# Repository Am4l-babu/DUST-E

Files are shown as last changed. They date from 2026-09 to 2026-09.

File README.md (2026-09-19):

# DUST-E

### The Uncooperative Waste Management System

A trash can that is technically intelligent and deliberately unhelpful.

It detects you. It looks at you. It opens for your rubbish, comments on your
throwing, and takes commands from a large industrial remote control that it
almost never obeys. There is a big illuminated button on the front labelled
**NORMAL MODE**. Press it and the bin becomes an ordinary, well-behaved
automatic dustbin — for about four seconds. Then a small hatch opens, a
comically oversized mechanical finger emerges, switches NORMAL MODE off, and
retracts.

That is the whole project. It works, it is safe, and it took a genuinely
unreasonable amount of engineering.

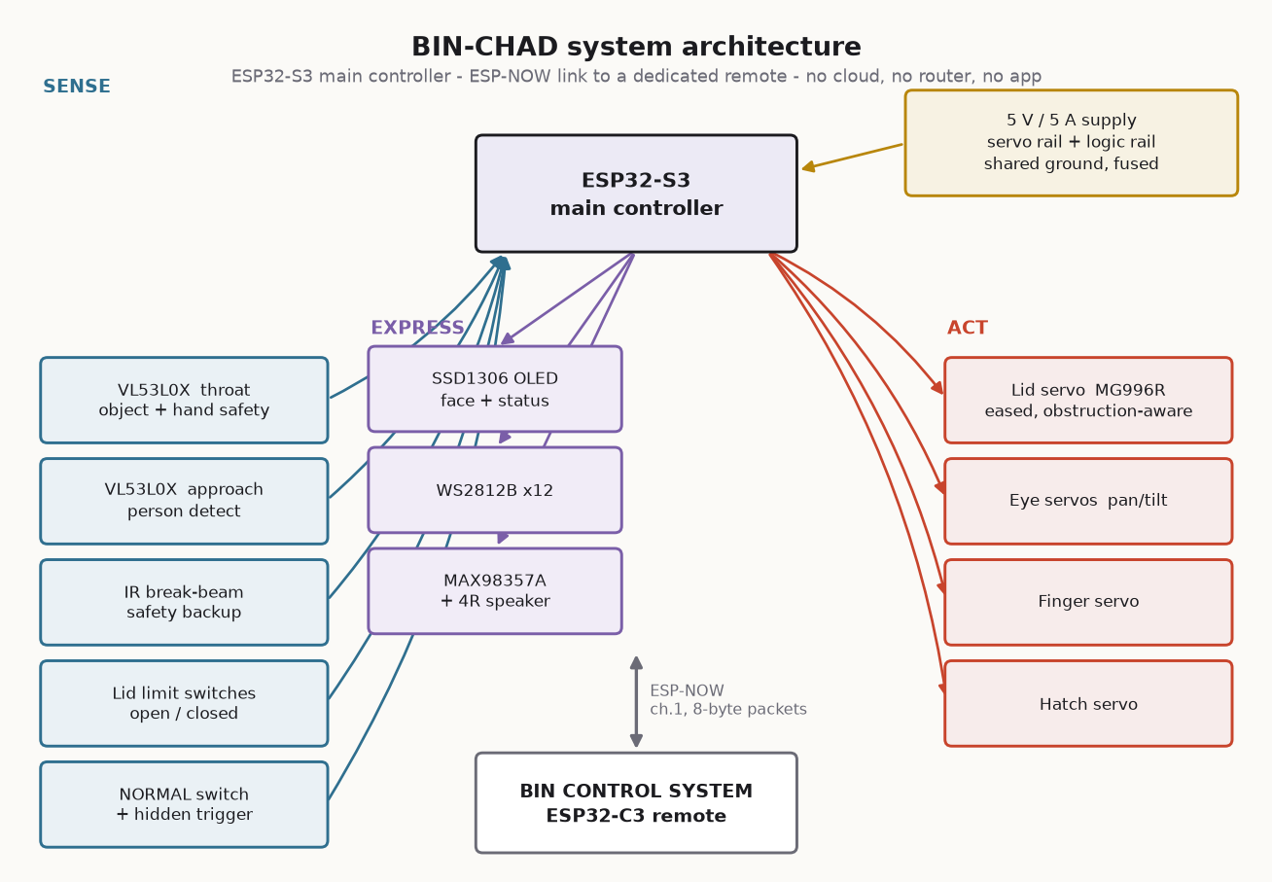
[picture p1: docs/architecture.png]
System architecture


---

## What is in this repository

| Path | Contents |
|---|---|
| `firmware/DustE/` | Main controller firmware (ESP32-S3). Arduino sketch, modular `src/` tree. |
| `firmware/DustERemote/` | Remote firmware (ESP32-C3). |
| `firmware/DustEWeb/` | The web remote: a second, simpler machine (ESP32 + L298N + two DC motors) that serves its own browser dashboard. The phone is its remote, its speaker and its eyes. See its [README](firmware/DustEWeb/README.md) and [PROTOCOL](firmware/DustEWeb/PROTOCOL.md). |
| `firmware/DustECam/` | Optional ESP32-CAM companion for the web remote: serves snapshots the phone runs its detector on. [README](firmware/DustECam/README.md). |
| `firmware/DustEBody/` | **In progress:** body controller firmware for the XIAO ESP32-S3 - motors, lid, LEDs, and the reflex safety that has the last word on anything that moves. [README](firmware/DustEBody/README.md). |
| `firmware/DustESensorNode/` | **In progress:** the UNO Q's own sensor firmware - HC-SR04 fan, IR throat, and the MOTION_OK safety pulse the XIAO body relies on. [README](firmware/DustESensorNode/README.md). |
| `brain/` | **In progress:** the autonomous-companion brain for the Arduino UNO Q (Python). Phase 1 (vision) done; Phase 2 (XIAO body link, safety validator, DRIVE/HW/DEBUG dashboard) nearly done. [README](brain/README.md). |
| `docs/COMPANION_ARCHITECTURE.md` | Analysis and phased plan for evolving the bin into an autonomous companion: reuse, conflicts, missing hardware, protocol, safety. |
| `docs/COMPANION_BOM.md` | Shopping list for the companion upgrade: what to buy per phase, sourced links, and why each part removes a specific failure. |
| `audio/` | The voice clips. The web remote's filesystem image ships them; more can be uploaded from its AUDIO tab. |
| `cad/` | Parametric OpenSCAD source for all 24 printed parts. |
| `docs/` | Generated diagrams (regenerate with `python tools/render_docs.py`). |
| `tools/` | Diagram renderer, WAV generator, and a static consistency checker. |
| `tests/` | Standalone bench bring-up sketches, one board/part at a time (not the `brain/` pytest suite). `xiao_motor_test/` (XIAO ESP32-S3 + L298N, `pio run` builds) and `cam_tilt_test/` (UNO Q camera tilt servo, D11, `arduino-cli compile` builds) are current; `l298n_motor_test/` and `obstacle_avoid_test/` are superseded records of the earlier UNO Q-driven wiring. |
| `BOM.csv` | Full bill of materials with prices and search links. |
| `PINOUT.md` | Exact GPIO map for both boards, plus the pins you must not touch. |
| `WIRING.md` | Power budget, distribution, connection tables, the servo cutoff circuit. |
| `BUILD_GUIDE.md` | Step-by-step assembly and calibration. |
| `CAD_README.md` | Every printed part: dimensions, print settings, the torque budget. |
| `FIRMWARE_README.md` | Module-by-module architecture, build setup, tuning. |
| `REMOTE_PROTOCOL.md` | ESP-NOW packet format and the mistranslation engine. |
| `TEST_PLAN.md` | Endurance, safety and reliability test checklist. |
| `TROUBLESHOOTING.md` | The eight failures you are actually going to hit. |
| `DEMO.md` | The two-minute demo script and the failure-proofing. |

---

## The five things it does

**1. It watches you.**
A VL53L0X pointing into the room notices someone approaching. The servo-mounted
eyeball turns toward them. The OLED says `OH NO.`

**2. It reacts to your throw.**
A second VL53L0X looks down the bin's throat. The lid opens on detection
(< 300 ms), waits, and decides whether the object actually went in.
It did: *"Acceptable."* It did not: two full seconds of silence, direct eye
contact, then *"My grandmother throws better."*

**3. It disobeys the remote.**
A dedicated ESP32-C3 remote — oversized, antenna'd, labelled
**PLEASE DO NOT TRUST** — sends honest ESP-NOW packets. The bin runs them
through a deterministic mistranslation engine: OPEN closes, CLOSE opens, LEFT
looks right, STOP makes everything faster, MUTE turns the volume up. The more
you press, the less it complies.

**4. It disables its own NORMAL MODE button.**
The signature mechanism. Documented in full in §"The punchline" below.

**5. It never hurts anyone.**
The lid is eased at both ends and cannot slam. Two independent sensors watch
the closing zone; either one stops the lid and reverses it, and the bin
apologises — the one thing it is never sarcastic about. Limit switches verify
both endpoints rather than trusting the servo angle. A master switch and a
firmware-controlled MOSFET both cut actuator power, and the safe state is the
default state.

---

## The punchline

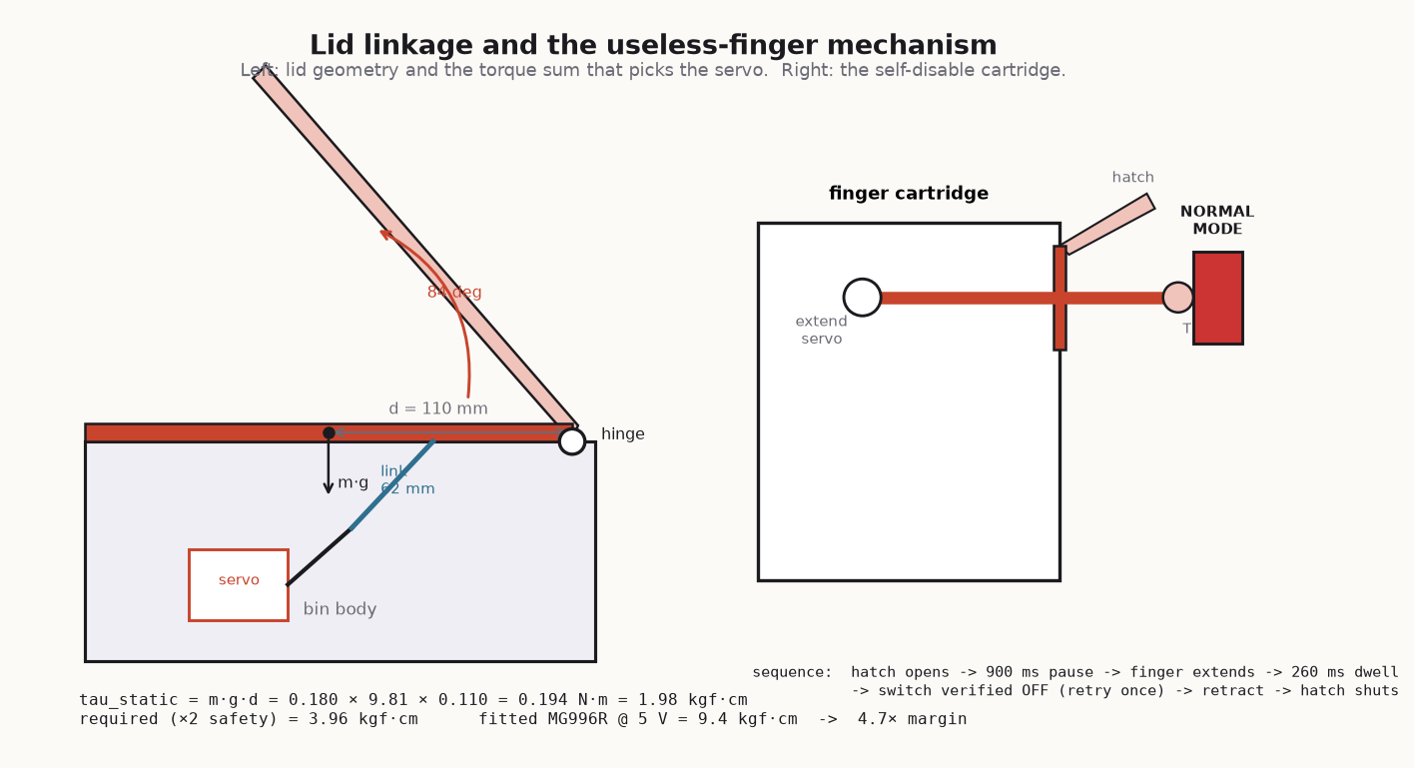
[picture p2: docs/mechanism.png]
Lid and finger mechanism


```
   user presses NORMAL MODE
            ↓
   bin becomes a completely normal automatic bin
            ↓
   ~4.5 seconds pass. The lid opens and closes properly. It is well behaved.
            ↓
   the eye turns, slowly, to look at the button
            ↓
   900 ms of nothing
            ↓
   a hatch opens in the front panel
            ↓
   900 ms of nothing (this pause is the joke)
            ↓
   an absurd finger extends and flips the switch OFF
            ↓
   the finger verifies the switch actually moved, and retries once if not
            ↓
   finger retracts, hatch closes
            ↓
   display:  NORMAL MODE CANCELLED
```

The eye looking at the button first is deliberate: telegraphing the move is
what turns a mechanism into a joke.

---

## The second machine: the web remote

`firmware/DustEWeb/` is a different build of the same idea. Instead of an
oversized labelled remote there is no remote at all — the ESP32 serves a
dashboard and your phone becomes the thing it disobeys.

It is a deliberately smaller machine: **ESP32 + L298N + two DC motors**, and
nothing else is required or pretended to exist. It drives, it argues, and it
files a written report about why it went the other way.

```
phone ──Wi-Fi / BLE / USB──> ESP32 ──> L298N ──> two motors
  │  ▲                         │
  │  └─ "play this" ───────────┼── sound bank    (31 events -> clips you upload)
  └──── "I saw a person" ─────┼── vision intake (the detector runs on the phone)
                               ├── web server + WebSocket
                               ├── personality engine  (7 traits, 9 moods)
                               └── safety layer        (has the last word)
```

The phone is the speaker and the eyes as well as the remote. Clips are
uploaded from the dashboard's AUDIO tab and assigned to events; the bin only
ever sends a tiny "play this" message, over Wi-Fi, Bluetooth and USB at once.
The VISION tab runs a person-and-object detector in the browser, on the
phone's camera or on an ESP32-CAM's snapshots, and reports what it saw.

The same priority order applies, and it shows up in the code rather than in
the marketing: the safety layer runs *before* the personality engine and
cannot be reached by it. STOP always stops, the controls are hold-to-drive,
the motors cut if the browser goes quiet for 1.5 seconds, and the dashboard
reports `BATTERY — NOT INSTRUMENTED` rather than inventing a percentage for a
sensor that is not fitted.

Built and verified with PlatformIO — `pio run` in that folder, then
`pio run -t uploadfs` for the dashboard. Full details, including the six
places where it deliberately departs from a literal reading of the brief, are
in [firmware/DustEWeb/README.md](firmware/DustEWeb/README.md).

---

## Design rules this project follows

**Serious engineering, ridiculous purpose.** Every subsystem is built as if it
mattered. None of it matters.

**The machine is the attraction.** No app, no cloud, no router, no dashboard.
ESP-NOW is peer-to-peer; unplug the venue's Wi-Fi and nothing changes.
(`firmware/DustEWeb/` deliberately trades this away for a browser
dashboard — but it carries its own access point, so it still needs nothing
from the venue.)

**Comedy never overrides safety.** The priority order, applied to every design
decision in this repo:

```
SAFETY → RELIABILITY → PHYSICAL COMEDY → MECHANICAL QUALITY
       → DEMO SPEED → VISUAL APPEAL → TECHNICAL COMPLEXITY
```

**Nothing blocks.** There is not a single `delay()` after `setup()` returns.
Everything is a `millis()` state machine, because the lid must keep checking
for fingers while audio plays, LEDs animate and packets arrive.

**Nothing is glued.** Every module comes out on M3 screws into heat-set
inserts. The electronics tray slides out of the back with the loom attached.
The lid lifts off by pulling one hinge pin. You will be debugging this on a
table with ten minutes to go.

**It degrades instead of failing.** A dead ToF sensor sets a flag and the bin
carries on. A missing WAV file is silent, not a crash. A lost remote produces
`REMOTE LOST / Good.` A lid fault shows `Have you tried turning me off?` and
keeps the rest of the machine alive.

---

## Quick start

```bash
# 1. Print the parts (see CAD_README.md for the plate order and settings)
openscad -o lid_frame.stl -D 'part="lid_frame"' cad/lid_mechanism.scad

# 2. Wire it (PINOUT.md, then WIRING.md)

# 3. Prepare the sounds
python tools/make_wavs.py            # generates placeholder clips into firmware/DustE/data/

# 4. Flash the bin
#    Arduino IDE -> firmware/DustE/DustE.ino
#    Board: ESP32S3 Dev Module | USB CDC On Boot: Enabled
#    Then: Tools -> ESP32 Sketch Data Upload  (writes data/ to LittleFS)

# 5. Flash the remote
#    Arduino IDE -> firmware/DustERemote/DustERemote.ino
#    Board: ESP32C3 Dev Module | USB CDC On Boot: Enabled

# 6. Calibrate (BUILD_GUIDE.md §7) - servo endpoints, then ToF thresholds

# Any time you edit a pin map, protocol.h, or settings.h:
python tools/verify_project.py       # duplicate GPIOs, diverged protocol
                                     # copies, undefined methods, broken doc
                                     # links, bad WAVs, contradictory settings
```

Build it in the order given in `BUILD_GUIDE.md` §1. One subsystem at a time,
each one tested before the next goes on. Wiring the whole thing and then
flashing it is how you end up debugging five problems at once at 3 a.m.

---

## Status and scope

**In the base build, and working:** lid with soft-close and obstruction
detection, dual ToF sensing, servo eye, OLED face, LED patterns, I²S audio,
the finger mechanism, the ESP-NOW remote, the mistranslation engine, the
personality state machine, self-test, and the hidden demo trigger.

**Deliberately optional** (in `README` terms: do not build these until the base
machine is boring and reliable):

- Camera-based face tracking and thrown-object detection (`OV2640`)
- Trajectory prediction
- Voice input
- Multiple stored personalities and per-user memory

The base machine must work with the camera physically removed. That is not a
style preference — it is the difference between a demo that survives a badly
lit conference hall and one that does not.

**Not verified here:** the DUST-E and DustERemote firmware has not been
compiled and the OpenSCAD has not been rendered in this environment — no
toolchain was available for them. (`firmware/DustEWeb/` is the exception:
it builds clean with no warnings under PlatformIO, and its LittleFS image
packs. It has not been run on hardware.) Treat the
first build as a bring-up, and expect to fix a missing include or a tight
tolerance. Every module was written against the documented library APIs and
reviewed by hand.

---

## Naming

The robot is **DUST-E**, and so is every machine in this repository: the bin
(`firmware/DustE`), its remote (`firmware/DustERemote`), the web rover
(`firmware/DustEWeb`), its camera (`firmware/DustECam`) and the brain
(`brain/dustebrain`). The name is drawn in
`display.cpp::bootScreen()` and on the remote's faceplate label.

People are expected to ask *"why does this exist?"*

The answer is: because we could build it.

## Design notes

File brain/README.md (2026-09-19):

# BRAIN

### The part of the trash bin that has opinions

The high-level brain of the DUST-E companion. It runs on the
**Arduino UNO Q's Linux side**: it sees, remembers, and decides. The ESP32 body
executes, and has the last word on anything that moves.

The full design, including why things are split this way, is in
[../docs/COMPANION_ARCHITECTURE.md](../docs/COMPANION_ARCHITECTURE.md).

**Status: phase 1 done, phase 2 nearly done.** Phase 1 is the camera,
detection, tracking and world model: it prints what the robot would believe
about the room. Phase 2 is the link to the XIAO ESP32-S3 body: the wire
protocol, the command validator, a Python reference implementation of the
body's reflex safety (section 7), `BodyLink` (section 8) - the real client -
and now the DRIVE + HW + DEBUG dashboard (section 9). `firmware/DustESensorNode/`
has been compiled and flashed on a real UNO Q (19 Sep 2026 - see its own
README section 5); `firmware/DustEBody/` still only builds, no XIAO has run
it yet. Nothing has driven a real motor.

```
USB camera ─► latest-frame grabber ─► detector (ONNX, ≤ 5 Hz) ─► torso signature
          ─► tracker ─► world model ─► events + LLM summary
```

---

## 1. What it tells you

```
[        0] VISION_ONLINE
[      400] PERSON_DETECTED      #1 4.8 m right FAR UNKNOWN
[     1200] PERSON_APPROACHING   #1 4.4 m right FAR APPROACHING
[     3600] PERSON_ZONE_CHANGED  #1 2.9 m ahead NOTICE APPROACHING previous=FAR
[     6200] PERSON_ZONE_CHANGED  #1 ~1.4 m ahead INTERACTION APPROACHING previous=APPROACH
[    11200] PERSON_WALKING_AWAY  #1 ~1.9 m ahead APPROACH WALKING_AWAY
[    13000] PERSON_LEAVING       #1 3.1 m ahead FAR WALKING_AWAY
[    17600] PERSON_LOST          #1 last_zone=FAR seen_for_s=14.6
```

`~` means the distance is an estimate the camera cannot vouch for (§4).

| Event | Meaning |
|---|---|
| `PERSON_DETECTED` | A new person, confirmed over several frames. One false-positive frame never gets greeted. |
| `PERSON_RETURNED` | Someone whose departure was announced is back: the "you again?" moment. |
| `PERSON_APPROACHING` / `PERSON_WALKING_AWAY` | Their own motion, with the robot's own motion subtracted once body telemetry exists. |
| `PERSON_LEAVING` | Walking away **and** beyond the notice zone. |
| `PERSON_LOST` | Out of view for `person_lost_s` (2.5 s). A detector blink is not a departure. |
| `PERSON_ZONE_CHANGED` | FAR / NOTICE / APPROACH / INTERACTION / TOO_CLOSE, with hysteresis. |
| `OBJECT_DETECTED` | A class not seen in the last 8 s. The same cup is news once. |
| `VISION_OFFLINE` | The camera went quiet. The summary then says *unknown*, never *nobody*. |

---

## 2. Run it

### Without any hardware (any PC with Python 3.10+)

```bash
cd brain
pip install numpy pyyaml pytest
python -m pytest                                   # 55 tests, no camera, no model
python -m dustebrain.apps.vision_node --sim walk_in  # a scripted person
```

Scenarios: `walk_in`, `flicker`, `returning`, `two_people_swap`,
`robot_drives_to_statue`, `person_with_cup`. Add `--realtime` to watch at real
speed, and `--snapshot 1` to print the LLM summary every second.

### On the UNO Q

```bash
sudo apt install python3-opencv python3-numpy python3-yaml python3-pytest
cd brain
python3 -m pytest
python3 -m dustebrain.apps.vision_node --bench 50      # acceptance: >= 3 Hz
python3 -m dustebrain.apps.vision_node --snapshot 2    # live
```

The camera goes through the **powered USB-C hub**: the UNO Q has one USB-C
port, and the camera, the ESP32 link and the microphone all need it.

Other flags: `--source clip.mp4` replays a recording at its own frame rate,
`--show` draws the tracks in a window (needs a display), `--serve 8081` does
the same drawing but serves it as an MJPEG stream any browser can open - the
one that matters on a headless UNO Q, where `--show` has no display to open -
and `--jsonl events.jsonl` keeps every event for later. `--show` and `--serve`
can run together; both draw from the same `_annotate()` call, so the bench
window and the browser tab show identical frames.

Verified against a real camera and a real HTTP client (19 Sep 2026, `--serve`
only - no UNO Q involved, a laptop webcam): `/` serves a page pointing at
`/stream.mjpg`, `/snapshot.jpg` returns a real, decodable JPEG matching the
camera's actual resolution, and `/stream.mjpg` delivers a live
multipart-replace stream. `brain/tests/test_vision_stream.py` covers the same
ground with synthetic frames, no camera required.

---

## 3. Detector model

Not committed: it is a binary, and its licence is its own. Export on a PC, not
on the board:

```bash
pip install ultralytics
yolo export model=yolov8n.pt format=onnx imgsz=320 opset=12 simplify=True
# copy yolov8n.onnx to brain/models/yolov8n-320.onnx
```

YOLOv8/YOLO11 (`[1, 84, N]`) and YOLOv5 (`[1, N, 85]`) output layouts are both
decoded. If you use a model with other classes, set `detector.labels` to its
class list in export order. The decoder refuses a label count that does not
match the tensor instead of guessing.

**Licence:** Ultralytics weights are AGPL-3.0. YOLOX-nano and NanoDet are
Apache-2.0 alternatives with the same box format, if that matters for you.

`detector.backend: none` runs the node with no detector at all. It then
reports no people, which in that configuration is the truth.

---

## 4. Calibration that actually matters

Distance comes from geometry, so these four numbers in `config/default.yaml`
(or your override file) decide whether "1.5 m" means 1.5 m:

| Key | How to get it |
|---|---|
| `camera.hfov_deg`, `camera.vfov_deg` | From the camera's datasheet, or measure: tape a 1 m ruler flat at a known distance and see how much of the frame it fills. |
| `geometry.camera_height_m` | Floor to lens, with the robot on its wheels. |
| `geometry.camera_pitch_deg` | Positive when tilted up. A phone inclinometer on the camera body is good enough. |

Then check: stand at 3 m with your feet in frame. The log should say ~3.0 m,
without a `~`.

**The honest limit.** A camera at bin height cannot see a whole standing
person up close. With the defaults (43° vertical FOV, 0.6 m, 5° up), feet leave
the frame at about 2 m. Closer than that, the estimate falls back to shoulder
width and is marked unreliable, but it is clamped to that 2 m bound. It can be
wrong, but not wrong in the direction that walks the robot into someone. A
wide-angle camera (VFOV ≥ 55°) moves the limit in. Collisions are the body's
range sensors' job, never the camera's.

---

## 5. Layout

| Path | Contents |
|---|---|
| `config/default.yaml` | Every threshold. The only place defaults live. |
| `dustebrain/config.py` | Loader: merges overrides, rejects unknown/missing keys, validates contradictions. |
| `dustebrain/events.py` | The event vocabulary for all phases. |
| `dustebrain/prng.py` | Bit-exact port of the firmware's xorshift32, so behaviour stays reproducible from a seed. |
| `dustebrain/vision/camera.py` | Latest-frame grabber thread, reconnect, file replay. |
| `dustebrain/vision/detector.py` | ONNX YOLO via `cv2.dnn` or onnxruntime; numpy decode + NMS. |
| `dustebrain/vision/appearance.py` | Torso colour histogram for short-term re-identification. RAM only. |
| `dustebrain/vision/tracker.py` | Association, track lifecycle, distance smoothing, radial velocity. |
| `dustebrain/vision/geometry.py` | Bearing, and ground/height/width distance with honest bounds. |
| `dustebrain/vision/stream.py` | `VisionStreamServer` - MJPEG-over-HTTP, viewable in a plain browser `<img>` tag. For a headless UNO Q, where `--show`'s local OpenCV window has no display to open. |
| `dustebrain/world/model.py` | People, identity across track breaks, zones, motion, objects, events, summaries. |
| `dustebrain/sim/scenario.py` | Deterministic scripted scenarios through the real geometry. |
| `dustebrain/apps/vision_node.py` | The phase-1 entry point. |
| `dustebrain/body/protocol.py` | Brain-to-body wire format: JSON lines, CRC-16, sequence numbers, a reader that survives boot-log noise. |
| `dustebrain/body/validator.py` | Source policy (the LLM cannot ask for a wheel speed), range clamps, rate limits, lower-only ceilings. |
| `dustebrain/body/simbody.py` | The body's reflex safety in Python: the reference the XIAO firmware is written against. |
| `dustebrain/body/link.py` | `BodyLink` - the real client: validate, frame, write; read, decode, update state. `SerialTransport` (pyserial) for the real port, `LoopbackPipe` for testing with no board. |
| `dustebrain/apps/body_probe.py` | Bring-up CLI: `--drive L R`, `--estop`, `--reset-estop`, a live status line. See firmware/DustEBody/README.md section 6. |
| `tests/` | One file per module; `test_world_model.py` is the phase-1 acceptance suite. |

Importing `dustebrain` does not import OpenCV. Only the camera, the detector
backends and `--show` do, so everything else runs on a machine with nothing
but numpy.

---

## 6. Verified how

- `python -m pytest`: 106 passed on Windows, Python 3.12, numpy 2.4 (no OpenCV
  installed, which is the point).
- Every `--sim` scenario produces the expected event sequence.
- With `opencv-python-headless` 5.0 in a clean virtualenv: the letterbox puts
  pixels exactly where the decoder expects, and a generated video replays
  through the camera thread and the full live loop (a colour-threshold
  stand-in for the model) to a clean exit.

**Not verified:** anything on a UNO Q, a real USB webcam, a real ONNX model
through `cv2.dnn` or onnxruntime, or detector speed on the A53 cores. The first
run on the board is a bring-up: run `--bench` before trusting `--snapshot`.

---

## 7. Phase 2: the body link

The XIAO is the only thing that can energise a motor, so its rules are the ones
that matter. They are written here first, in Python, so the failsafe matrix can
be tested before a wire is soldered - and so the firmware has an exact
specification instead of a paragraph of prose.

**The wire format** is one JSON object per line with a CRC:

```
{"v":1,"seq":1042,"t":583211,"type":"vel","l":35,"r":31,"ttl":300}*7A3F
```

Readable in a serial monitor on purpose: when the robot misbehaves at a demo,
the diagnosis has to be visible in a terminal. The CRC is there because the USB
line shares a chassis with motor wiring. A corrupted line is dropped and
counted, never guessed at, and the reader skips the ESP32 boot log without
complaining.

**The validator** is the box between everything clever and everything physical:

| Rule | Why |
|---|---|
| `vel` from `src: "llm"` is refused | The model may ask to look at someone; it may not ask for a wheel speed. Enforced in code, not in a prompt. |
| `reset_estop` only from `src: "manual"` | Clearing an emergency stop is a human decision. |
| `estop` from anyone, never rate limited | Stopping is always allowed. |
| Autonomous speed capped below manual | 45 % against 70 % by default. |
| `limits` may only **lower** a ceiling | No message in this protocol raises one. |

**The reflex safety** (`simbody.py`), in the order the body applies it:
E-stop latch, battery critical, link timeout, command TTL, MOTION_OK veto,
then ceiling and ramp. The MOTION_OK veto is worth spelling out: the UNO Q MCU
toggles one wire while its sensors see no hazard, and the body requires *edges*,
not a level. A wall, a cliff, a bumper, a crashed MCU, a hung loop and a broken
wire all produce the same thing - no pulses - and are all handled the same way:
forward motion blocked, a short slow reverse allowed to escape, then a cooldown
so escaping cannot become a habit.

`tests/test_simbody.py` is the failsafe matrix from
[the architecture doc](../docs/COMPANION_ARCHITECTURE.md) section 8.1, as tests.
When the firmware exists, the same scenarios get pointed at the real board: if
the firmware disagrees with any of them, the firmware is wrong.

**Not verified:** no serial port, no XIAO, no motor has been involved. This is
a specification with tests, not a driver.

---

## 8. Phase 2b: the real client

`BodyLink` is what `simbody.py` was written to be tested against - the actual
brain-side object that will talk to a real board:

```python
from dustebrain.config import load_config
from dustebrain.body.link import BodyLink, SerialTransport

cfg = load_config()
link = BodyLink(SerialTransport("/dev/ttyACM0"), cfg.body)

while True:
    t = ...                       # milliseconds, monotonic
    link.tick(t)                  # sends its own hello/heartbeats, drains the port
    if link.state.handshaken:
        link.velocity(30, 30, t, src="nav")
```

Every outbound call goes through the same `Validator` the tests exercise -
`link.send(P.VEL, src="llm", ...)` is refused locally, before a byte reaches
the wire, exactly as `test_validator.py` says it must be. `BodyState` tracks
what the brain currently believes: the handshake, the hardware inventory the
body reported, the last telemetry, and - the part worth reading twice -
`online()`, which answers "is this still trustworthy" rather than "did it ever
say hello". A body that stops sending telemetry stops being online, even if
the last thing it reported was perfectly healthy.

**`LoopbackPipe`** is the reason `test_body_link.py` can prove all of this
without a port: it is a real in-memory duplex pipe, wired directly to a real
`SimBody`. Nothing in that test file is mocked - `Validator`, `Framer`,
`protocol.encode`, the bytes, `protocol.decode`, `SimBody.handle()`, the reply
bytes, back through `protocol.decode`, into `BodyState` - the entire stack
runs for real, twice per message.

**`python -m dustebrain.apps.body_probe`** is the tool for the bring-up
procedure in `firmware/DustEBody/README.md` section 6: watch the handshake,
watch telemetry, and - **wheels off the ground** - send a short drive pulse,
an E-stop, or a reset. It does nothing `BodyLink` itself cannot do; it is a
terminal wrapped around the same calls.

**Not verified:** no real serial port, no real XIAO, has been involved. A bad
port name (`body_probe --port COM255`) does fail cleanly with a clear error
and exit code 2, which is the one thing that was checked against reality.

---

## 9. Phase 2: the dashboard

`dustebrain.dashboard.DashboardServer` is the DRIVE + HW + DEBUG web
dashboard the Phase 2 acceptance check names. It is a thin HTTP wrapper
around `BodyLink` - stdlib `http.server`, no new dependency, no WebSocket:
the page polls `/api/status` every 150 ms and, while a drive button is held,
resends `/api/drive` every 100 ms so the command never runs out its TTL
mid-press. Every command it sends is `src="manual"`, through the same
`Validator` as `body_probe.py` - this page can do nothing the CLI could not
already do, and the XIAO's reflex layer still has the final say regardless of
what either one asks for.

```
python -m dustebrain.apps.dashboard --sim          # no hardware - drives an in-process SimBody
python -m dustebrain.apps.dashboard --port COM5    # a real body
```

`brain/tests/test_dashboard.py` is a real integration test: real HTTP
requests, over a real socket, against a real `DashboardServer` wired to a
real `SimBody` the same way `--sim` runs it - nothing mocked, same discipline
as `test_body_link.py`. It is also what found a real, pre-existing gap: see
`docs/COMPANION_ARCHITECTURE.md` section 9.2's note on `manual_max_pct` never
actually being reachable as a ceiling, in either `simbody.py` or the real
firmware.

**Not verified:** no browser has opened the page, and no real XIAO has driven
the DRIVE tab. `--sim` mode and the automated test are what exist instead.

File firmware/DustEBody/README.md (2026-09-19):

# DUST-E BODY

### The part that moves, and the part that says no

Firmware for the **Seeed XIAO ESP32-S3** (plain, not Sense). The brain — the
Arduino UNO Q's Linux side — decides what the robot should do. This board
executes it, and has the last word on anything that moves.

Design and the reasoning behind the split:
[../../docs/COMPANION_ARCHITECTURE.md](../../docs/COMPANION_ARCHITECTURE.md).

---

## 1. Hardware

| XIAO pad | GPIO | Net | Fit this too |
|---|---:|---|---|
| D0 / D1 | 1, 2 | L298N `IN1` / `IN2`, left motor | **10 kΩ pull-down on each** |
| D8 / D9 | 7, 8 | L298N `IN3` / `IN4`, right motor | **10 kΩ pull-down on each** |
| D2 | 3 | WS2812B data (12 pixels) | 330 Ω in series |
| D3 | 4 | Lid servo signal | servo power from the servo rail, **never** the XIAO |
| D4 / D5 | 5, 6 | I²C — throat ToF (not fitted yet), PCA9685 later | 4.7 kΩ pull-ups |
| D7 | 44 | `MOTION_OK` from the UNO Q MCU D9 | **100 kΩ pull-down** |
| D6, D10 | 43, 9 | spare, reserved for I²S | — |
| USB-C | — | link to the UNO Q, through the powered hub | — |

`ENA`/`ENB` jumpers on the L298N stay **on**: the driver is controlled on its
IN pins, which costs four GPIOs instead of six.

**The pull-downs are not optional.** While this board is resetting, being
flashed or unpowered, its pins are inputs. Without the pull-downs the L298N
inputs float and a motor can twitch. They cost pennies and they are the
difference between a safe power-up and a surprise.

---

## 2. Build and flash

```bash
cd firmware/DustEBody
pio run              # build
pio run -t upload    # flash
pio device monitor   # watch the [hb] line and the telemetry
```

Arduino IDE works too: open `DustEBody.ino`, board **XIAO_ESP32S3**, and set
**USB CDC On Boot = Enabled** — `Serial` is the native USB port and is also the
brain link.

Libraries (PlatformIO installs them automatically): ArduinoJson 7, Adafruit
NeoPixel, ESP32Servo.

---

## 3. What it refuses to do

This is the whole point of the board, so it is worth stating plainly.

| Situation | What happens |
|---|---|
| The brain stops sending for 300 ms | Motors hard stop. A crashed brain, a yanked cable and a hung Linux side are the same failure here. |
| A velocity command is not refreshed | Its TTL expires (500 ms max) and the target ramps to zero. Normal, not a fault. |
| `MOTION_OK` pulses stop | Forward motion blocked within ~150 ms. A short, slow reverse is allowed to escape, then a cooldown. |
| The E-stop is hit | Latched. Motor power is also cut in hardware, upstream of this board. |
| `reset_estop` arrives while the motors are still turning | Refused, with `E_BUSY`. |
| Anything asks for more than the ceiling | Clamped to 45 % autonomous / 70 % manual. The `limits` message can only ever **lower** it. |
| A command arrives before `hello` | Refused. The safe state is the default state. |
| A line arrives with a bad CRC | Dropped and counted. Never half-parsed, never guessed at. |
| A command names hardware that is not fitted | Refused with `E_NOT_INSTALLED` and a reason — not silently ignored. |

`MOTION_OK` deserves the detail: the UNO Q MCU toggles one wire while its
sensors see no hazard, and this board counts **edges**, not a level. A wall, a
cliff, a bumper, a crashed MCU, a hung loop and a cut wire all produce the same
thing — no pulses — and all get the same answer.

---

## 4. Architecture

```
loop():  brainLink.poll()    commands land first
         reflex.enforce()    then safety decides what survives
         motors.tick()       then, and only then, the wheels hear about it
         lid / leds          expression, which cannot move the wheels
         telemetry
```

There is no `delay()` after `setup()` returns. That is what makes every timeout
in the table above mean anything.

| File | Contents |
|---|---|
| `src/config/pins.h` | The GPIO map, and why each pin is where it is. |
| `src/config/settings.h` | Every tunable number. The same values as the `body:` block in `brain/config/default.yaml`. |
| `src/link/brainLink.*` | JSON lines + CRC-16, command dispatch, telemetry, honest hardware inventory. |
| `src/safety/reflex.*` | The rules above, in the order they are applied. The `MOTION_OK` ISR lives here. |
| `src/motor/motors.*` | L298N on four pins, ramp, min-duty lift, ceiling. Adapted from `DustEWeb`. |
| `src/hw/lid.*` | Cosine-eased lid, auto-detach when parked. |
| `src/hw/leds.*` | 12-pixel WS2812B patterns, non-blocking. |
| `src/core/crc16.h` | CRC-16/CCITT-FALSE. Check value for `123456789` is `0x29B1`. |

**The specification lives in Python.** `brain/dustebrain/body/simbody.py` is a
reference implementation of the reflex rules, and `brain/tests/test_simbody.py`
is the failsafe matrix as 20 tests. This firmware is written to match it. If
the two disagree, this firmware is wrong.

---

## 5. Not yet on this board

Refused with `E_NOT_INSTALLED` until the hardware and its driver arrive
together — the inventory flags at the bottom of `settings.h` are the seam:

- **Throat ToF (VL53L0X).** Until it is fitted, the lid closes on the slow
  profile only and reports `lid_safety: degraded_slow_close`. It cannot detect
  an obstruction, and it does not claim to.
- **Speaker (MAX98357A).** I²S needs three pins and two are spare, so fitting
  the amp also means fitting a PCA9685 and moving the lid servo onto it.
- **Eye servo, finger.** No pads left; both arrive with the PCA9685.
- **Battery.** Measured by the INA219 on the UNO Q sensor node and forwarded
  over the link. Until then telemetry reports `battery_mv: null` rather than a
  fabricated number.

---

## 6. Verified how

`pio run` builds clean for `seeed_xiao_esp32s3` — 6.2 % RAM, 9.2 % of the app
partition. The only warnings come from inside ESP32Servo.

**Not verified:** none of this has run on a XIAO, driven a motor, or exchanged
a byte with a UNO Q. There is no serial client on the brain side yet. Treat the
first power-up as a bring-up, **with the wheels off the ground**, in this
order: `[hb]` line appears → `hello` handshake → MOTION_OK pulses seen in
telemetry → then, and only then, a velocity command.

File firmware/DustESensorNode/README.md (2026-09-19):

# DUST-E SENSOR NODE

### The UNO Q's half of physical safety

Firmware for the **Arduino UNO Q, MCU side** (STM32U585, Zephyr-based Arduino
core, board `arduino:zephyr:unoq`). This board owns every sensor that can stop
the robot and drives no motor. It talks to the XIAO body over exactly one
signal.

Design and reasoning: [../../docs/COMPANION_ARCHITECTURE.md](../../docs/COMPANION_ARCHITECTURE.md)
section 6.2. The XIAO side of this conversation is
[../DustEBody/](../DustEBody/README.md).

---

## 1. The one signal that matters: MOTION_OK

This board's **D9** goes to the XIAO's **D7**. It is a pulse train, not a
level: this loop toggles it every pass while nothing it can see is a hazard,
and holds it low the instant something is. The XIAO requires at least two
edges inside a 150 ms window before it will drive forward at all
(`firmware/DustEBody/src/safety/reflex.cpp`).

That design means a crashed MCU, a hung loop, a cut wire, an obstacle, a cliff
and a pressed bumper all produce **exactly the same signal**: no pulses. The
XIAO does not need to know which one happened to do the right thing. It only
needs to know that this board is no longer vouching for the space ahead.

Worst-case loop period here is one `pulseIn()` timeout (12 ms, one HC-SR04 read
per pass, round-robin). That leaves enormous margin under the XIAO's 150 ms
window - this board does not need to be fast, only reliably not-stuck.

---

## 2. Wiring

Same physical pins as `firmware/UselessBox/UselessBox_UnoQ/` - this is a
different program for the same bench wiring, not a new harness. Only the six
pins the L298N and the flip-switch servo used to occupy are repurposed, because
both of those moved to the XIAO.

| Pin | Net | Status |
|---|---|---|
| D2 / D4 | HC-SR04 #1 TRIG / ECHO | fitted (ECHO through a 5 V→3.3 V divider) |
| A0 / A1 | HC-SR04 #2 TRIG / ECHO | fitted |
| A2 / A3 | HC-SR04 #3 TRIG / ECHO | fitted |
| D3 | active buzzer | fitted |
| D12 | NORMAL MODE switch | fitted, `INPUT_PULLUP` |
| D13 | IR throat sensor | fitted |
| SDA/SCL (`Wire2`) | SSD1306 OLED | fitted |
| SDA/SCL (`Wire2`) | INA219 battery monitor @0x40 | **not fitted** - [BOM row 4](../../docs/COMPANION_BOM.md) |
| D5 / D6 | `BUMPER_L` / `BUMPER_R` | **not fitted** - row 9 |
| D7 / D8 | `CLIFF_L` / `CLIFF_R` | **not fitted** - row 8 |
| D9 | `MOTION_OK` → XIAO D7 | fitted, this board is the source |
| D10 | `ESTOP_SENSE` | **not fitted** - fit with the E-stop, row 1 |
| D11 | camera tilt servo | fitted (19 Sep 2026) - see section 6 below. Not driven by this sketch yet |

Bumpers and the E-stop sense contact are wired **NC to ground through a
pull-up**: the resting, safe state is a closed circuit reading LOW. A press
*or* a broken wire both open the circuit and read HIGH - deliberately the same
outcome, because "I don't know" and "it's pressed" should never be told apart
by a robot deciding whether to keep driving.

---

## 3. Hardware inventory - honesty, not auto-detection

None of the new sensors can be detected on these pins, so nothing is guessed.
Flip a flag in the sketch at the same time the part is soldered in:

```cpp
#define HW_CLIFF     0   // TCRT5000 x2
#define HW_BUMPERS   0   // micro limit switch x2
#define HW_ESTOP     0   // aux NC contact on the mushroom switch
#define HW_BATTERY   0   // INA219 on Wire2 @0x40
```

An uninstalled sensor is **left out of the hazard vote entirely** - not read
as "safe" (which would be worse than not having it) and not read as a
permanent hazard (which would just wedge MOTION_OK forever on an empty pin).
Today, with cliff, bumpers, E-stop-sense and battery all unfitted, MOTION_OK
tracks the ultrasonic fan and the IR throat sensor only. **Autonomous roaming
must not be enabled** (`docs/COMPANION_ARCHITECTURE.md` §7, `docs/COMPANION_BOM.md`
§2) until the cliff sensors and bumpers exist - that is a brain-side
configuration decision, not something this firmware can enforce by itself.

The periodic status line on the serial console (`[sensor] hazard=...`) always
prints every channel's raw reading, `-1` for anything not installed, so a
bring-up can be checked against what is actually true.

---

## 4. Build and flash

Arduino IDE only - there is no PlatformIO board definition for the UNO Q yet
(the same limitation noted in `tests/l298n_motor_test/platformio.ini`).

1. Board: **Arduino UNO Q**.
2. Libraries: `Adafruit GFX Library` (only `drawPixel` is used; the OLED is
   driven directly because neither `Adafruit_SSD1306` nor U8g2's hardware-I2C
   path reaches the header pins' `Wire2` bus on this core).
3. Open `DustESensorNode.ino`, upload.
4. Serial monitor at 115200 baud.

---

## 5. Verified how

**Compiled and flashed on real hardware (19 Sep 2026)**, via `arduino-cli`
(`arduino:zephyr:unoq`, board core `arduino:zephyr@1.0.0`) against a UNO Q
connected over USB (`COM4` for the MCU/serial interface; the same composite
device also exposes an ADB interface and a network port for the Linux side).
This is the first time this sketch has run on hardware rather than just being
read against the documented API.

That first compile caught a real bug: `Serial.printf(...)` does not exist on
this core (`Serial` here is Zephyr's `BridgeMonitor<>`, which only has
`print()`/`println()`) - both status-print call sites were rewritten to plain
`print()` chains. Fixed and confirmed by a clean compile (13% flash, 17% RAM).

Live serial output after flashing:

```
[sensor] hazard=0 (clear) us=-1/-1/-1 cliff=-1,-1 bump=-1,-1 estop=-1 normal_sw=0 motion_ok=1
```

Read against the wiring table above: `cliff=-1,-1 bump=-1,-1 estop=-1` is
correct - those `HW_*` flags are `0` (not fitted) on this board today, so the
sketch is correctly leaving them out of the hazard vote rather than guessing.
`us=-1/-1/-1` is `readDistanceCm()`'s honest "no echo within the 12 ms/~2 m
timeout" value (line ~251) - on this particular bench run it never saw a
return echo from any of the three HC-SR04 units in an 8-second sample. That is
consistent with either the ultrasonic fan not being wired to *this specific*
board right now, or genuinely nothing within ~2 m of all three sensors; it is
**not** distinguishable from serial output alone, by design (a fabricated
reading would be worse than an honest "don't know"). Wave a hand within ~30 cm
of each sensor and re-read the line to tell those two cases apart before
trusting the ultrasonic fan for anything.

Not yet verified: the OLED face render, the buzzer, and the NORMAL MODE
switch under an actual press (this run only sampled its resting `normal_sw=0`
state).

---

## 6. Camera tilt servo (D11) - fitted, not yet driven

A servo tilts the USB webcam up/down. It lives on D11 because that pin was
already reserved and unused (the flip-switch servo moved to the XIAO's lid
early on - see `docs/COMPANION_ARCHITECTURE.md` section 6.2 - and nothing
had claimed D11 since). This sketch does not attach or move it yet.

**Bring-up test:** `tests/cam_tilt_test/` - a standalone sketch (Arduino IDE
/ `arduino-cli` only, same as this one). Confirmed by a real compile against
`arduino:zephyr:unoq` (19 Sep 2026, 11% flash) that Arduino's official
`Servo` library works on this core and this pin. **Not flashed or run**: the
camera mount's actual mechanical range (how far it can tilt before something
binds) is not known from here, so the test deliberately starts with a narrow,
slow sweep (90° ± 20°, one degree at a time) rather than the servo's full
range, and needs a human watching the first run before anything wider is
tried.

**Not yet decided:** how the brain's vision pipeline would actually command a
tilt angle. Today this sketch only talks to the Linux side one-way, over its
debug console (`Serial`, which is Zephyr's `BridgeMonitor<>` tunnelled
through the UNO Q's own Linux↔MCU bridge - a different channel from the
brain↔XIAO wire protocol in section 9 of the architecture doc). Commanding
the servo from `dustebrain.vision` would need a real two-way channel on that
bridge, which does not exist yet - a separate task from wiring up the servo
itself.

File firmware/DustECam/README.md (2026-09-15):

# DUST-E CAM

### An ESP32-CAM that lends the web remote a second pair of eyes

The web remote in `../DustEWeb/` does its person-and-object detection in
the phone's browser, on the phone's own camera. That works, but it means the
phone has to be pointed at the room, and the phone's camera API needs a
"secure page" flag on plain `http://`. This board is the alternative: bolt an
ESP32-CAM to the bin, and the phone runs the same detector on **its**
pictures instead — no flag, and the phone stays in your hand.

It runs **no detector itself**. An ESP32 cannot run a useful object detector,
and this project does not fake sensors. What it does:

| Route | What |
|---|---|
| `/capture` | One fresh JPEG, with `Access-Control-Allow-Origin: *` so the browser is allowed to read its pixels. This is what the VISION tab polls. |
| `/stream` | MJPEG, for a human to look at. |
| `/status` | JSON: camera ok, frame size, uptime, heap, PSRAM, RSSI. |
| `/` | A page that shows the stream and links the above. |

## Hardware

| | |
|---|---|
| Board | AI-Thinker ESP32-CAM (OV2640, 4 MB PSRAM). Other modules have a different pin map — edit the top of the sketch. |
| Power | 5 V, and a supply that can actually deliver it; brownouts on Wi-Fi bursts are the classic ESP32-CAM fault. |
| Programming | An ESP32-CAM-MB base, or a USB-UART on U0T/U0R with IO0 held to GND during reset. |
| Wiring to the bin | None. It talks over Wi-Fi. |

## Network

By default it joins the bin's own access point (`DUST-E-SETUP` /
`dustebin`, from `DustEWeb/src/config/settings.h`), so the whole thing
works in a room with no Wi-Fi: phone, bin and camera are all on the bin's
AP. If the bin is on a house network instead, put the same SSID and password
at the top of `DustECam.ino`.

It answers at `http://trashcam.local/` (mDNS) or the IP printed on the serial
port at boot. On the bin's AP the first station is usually `192.168.4.2`.
Android is bad at mDNS; use the IP.

## Build

```bash
cd firmware/DustECam
pio run             # builds clean, 28 % of the 3 MB app partition
pio run -t upload
```

Or Arduino IDE: Board **AI Thinker ESP32-CAM**, Partition Scheme **Huge APP**.
No libraries to install — the camera driver and the HTTP server are part of
the ESP32 core.

## Using it

1. Power the camera, wait for the serial port to say `camera: ok` and print
   an address.
2. On the bin's dashboard, **VISION** tab, pick **ESP32-CAM SNAPSHOTS**,
   enter the address, **START**. The tab polls `/capture` about four times a
   second and draws the boxes on the picture.
3. Detections go to the bin as `src: "cam"`. Everything after that is the
   same as with the phone camera.

## If a detector is ever added

`reportToBin()` at the bottom of the sketch already knows how to POST a
result to the bin's `/api/vision`. It is unused today because nothing on
this board has anything honest to report. If a person-detection model is
put on here (the TFLite Micro `person_detection` example does run on this
module at 96×96 greyscale), call it from `loop()` and the bin will treat the
report exactly like one from the phone.

## Verified how

Compiles clean with `-Wall` under PlatformIO. Not run on hardware in this
environment.

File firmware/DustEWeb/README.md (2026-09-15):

# DUST-E WEB REMOTE

### A browser-based command centre for a trash can that has developed an attitude

There is no physical remote. Your phone is the remote. The ESP32 serves a
dashboard, takes commands over a WebSocket, and then decides how much of each
one it feels like honouring.

```
USEFULNESS       0%
COMPLEXITY     150%
DRAMA          200%
OBEDIENCE        4%
ENGINEERING    100%
```

This is a **separate machine** from DUST-E. DUST-E is an ESP32-S3 with
servos, sensors and an ESP-NOW link to a physical remote. This is a plain
ESP32 driving an L298N and two DC motors over Wi-Fi. They share no pins, no
protocol and no firmware.

The phone is also the **speaker** and the **eyes**. The bin has neither. It
sends a tiny "play this" message (over Wi-Fi, Bluetooth and USB, all at once)
and the phone plays a clip you uploaded from the AUDIO tab; the phone's
camera (or an ESP32-CAM's snapshots) runs a person-and-object detector in the
browser and tells the bin what it saw. §5 and §6 below.

---

## 1. Hardware

Everything the current build needs:

| Part | Notes |
|---|---|
| ESP32 dev module | Classic ESP32, not S3. |
| L298N motor driver | Any of the common red breakout boards. |
| 2 × DC motors | Geared, whatever the chassis takes. |
| Motor supply | 6–12 V into the L298N's `+12V`. **Not** the ESP32's 5 V pin. |

### Wiring

The pin map is the one already proven on the bench by
`tests/l298n_motor_test` — if you have run that sketch, you are already wired.

| L298N | ESP32 | Purpose |
|---|---|---|
| `ENA` | GPIO 18 | left motor speed (PWM) |
| `ENB` | GPIO 19 | right motor speed (PWM) |
| `IN1` | GPIO 27 | left direction |
| `IN2` | GPIO 26 | left direction |
| `IN3` | GPIO 25 | right direction |
| `IN4` | GPIO 33 | right direction |
| `GND` | `GND` | **mandatory** — the common ground |
| `+12V` | motor supply | external, never the ESP32 |

Remove the L298N's 5 V regulator jumper if you are feeding it more than 12 V,
and do not try to power the ESP32 from the L298N's 5 V output while the motors
are stalling — the brownout will reboot the board mid-drive.

> If a motor does not spin at all, check the common ground first. It is the
> reason nine times out of ten.

---

## 2. Build and flash

### Libraries

| Library | Version |
|---|---|
| `bblanchon/ArduinoJson` | 7.x (the v7 `JsonDocument` API) |
| `esp32async/AsyncTCP` | 3.x |
| `esp32async/ESPAsyncWebServer` | 3.x |
| `h2zero/NimBLE-Arduino` | 2.x (the Bluetooth trigger link; set `DUSTE_BLE 0` in `settings.h` to leave it out) |

### PlatformIO (what this was built and verified with)

```bash
cd firmware/DustEWeb
pio run              # build
pio run -t upload    # flash the firmware
pio run -t uploadfs  # flash data/ to LittleFS  <- do not skip this
```

The partition table is `no_ota.csv` (2 MB app, 1.9 MB filesystem): Wi-Fi plus
the async web server plus BLE is about 1.2 MB of code, and the sound clips
need room. Flashing this over a board that had the default layout **erases
the old filesystem**, so run `uploadfs` again afterwards.

### Arduino IDE

Open `DustEWeb.ino`. Board: **ESP32 Dev Module**, Partition Scheme:
**No OTA (2MB APP/2MB SPIFFS)**. Install the four libraries above through
the Library Manager, then use **Tools → ESP32 Sketch Data Upload** to write
`data/` to LittleFS.

**Both steps are needed.** The firmware holds a minimal fallback page in
PROGMEM, so a board with an empty filesystem still serves a working four-button
control pad and an emergency stop rather than a blank screen — but the real
dashboard lives in `data/`.

### First run

With no stored Wi-Fi credentials the board brings up its own access point:

```
SSID      DUST-E-SETUP
password  dustebin          (change it in settings.h or the SETUP tab)
open      http://192.168.4.1
```

Enter your network in the **SETUP** tab and it restarts onto it. After that:

```
http://dust-e.local
```

The serial port prints the address either way, at 115200 baud.

---

## 3. Using it

**Hold to drive.** The joystick and the D-pad are dead-man's switches. While
held, the browser repeats your intent every 100 ms; when you let go it sends a
stop. If the browser goes quiet for 450 ms the ESP32 stops the motors on its
own, and if the WebSocket drops it stops them immediately. The browser is
never the only thing keeping the robot safe.

This also means a *delayed* command only lands if you are still holding the
control when the bin finally gets round to it. That is the joke working as
intended.

### The buttons

| Button | What it does |
|---|---|
| Joystick / D-pad | Drive. Eight directions plus stop. |
| STOP | Stops. Always. See §4. |
| SPEED | What you would like. Not necessarily what you get. |
| OPEN / CLOSE | Lid commands. No servo is fitted, so the lid state is labelled **SIMULATED**. |
| PLEASE | Raises obedience and trust a little. Response: *"Maybe."* |
| SORRY | Reduces anger — with diminishing returns. Apologise too often and you get *"Too late."* |
| PANIC | Theatrical. Raises anger and confusion, flips the face, expires after 9 s. Moves nothing by itself. |
| DO NOTHING | Does nothing, with a full report. Never transformed. |
| RETURN TO NORMAL | Grants genuine normal behaviour for 0.6–4.5 s, then takes it away again. |
| EMERGENCY STOP | Real. See §4. |

### Drive modes

| Mode | Behaviour |
|---|---|
| `NORMAL` | Genuine debug mode. Identity transform, zero delay, permanent. |
| `UNCOOPERATIVE` | The default show. Weighted misbehaviour driven by the traits. |
| `REVERSE` | Deterministic inversion. Predictable, and your own fault. |
| `CHAOS` | Seeded pseudo-random mapping that changes between presses. |
| `DRUNK` | Mostly tries, with a wandering steering bias and delays. |
| `LAZY` | Obeys slowly. Acceleration drops to a crawl. |
| `ANGRY` | Zero compliance, mostly random substitutions. |
| `SLEEP` | Ignores about three commands in four. |
| `PANIC` | Short delays, high randomness, maximum drama. Auto-expires. |

### Personality

Seven traits — anger, trust, happiness, confusion, boredom, obedience,
rebellion — drift over time and react to what you do. Mashing the same
direction raises anger. Leaving it alone raises boredom. Rebellion is derived
from anger and obedience rather than stored independently, so the readout can
never disagree with the behaviour.

Once anger passes 70, the probability of compliance is **exactly zero** and
stays there until it decays.

Behaviour is driven by one seeded xorshift32 stream, printed at boot:

```
[    1243] BOOT   personality seed 0x9F3A1C22 mood NORMAL
```

Same seed plus the same presses gives the same sequence of wrong answers. Pin
it in NVS (key `seed` in namespace `trashbot`, see `NVS_NAMESPACE`) to rehearse a demo or reproduce
a complaint. Zero means "surprise me".

---

## 4. Safety

The one rule: **safety runs before the personality engine, and the personality
engine cannot reach back into it.** It cannot clear the emergency stop, extend
a timeout, raise a speed limit, or delay a stop.

Four independent inhibits:

| Inhibit | Trigger | Effect |
|---|---|---|
| Emergency stop | The red button | Latched. Motors cut. Cleared only by an explicit reset. |
| No clients | Browser closed | Motors cut immediately. |
| Link timeout | 1500 ms of silence | Motors cut. |
| Drive timeout | 450 ms without drive intent | Target ramped to zero. |

Below all of that, the motor layer enforces a maximum duty and an acceleration
limit, and deceleration is always allowed to outrun acceleration.

The emergency stop is latched in the network callback the instant the frame
arrives, without waiting for the main loop, and requires a deliberate
**RESET SAFETY SYSTEM** press to clear.

---

## 5. Sound: the phone is the speaker

There is no speaker on the board and no audio data ever leaves it. When
something happens, the firmware sends a message naming the event and the
clip, and every phone with the dashboard open plays that clip. This makes
the phone in your hand the bin's voice, which is the joke: it talks to you
through the thing you are trying to control it with.

**AUDIO tab, top to bottom:**

1. **ENABLE SOUND ON THIS DEVICE.** Browsers will not play audio until you
   have tapped something. Tap this once per visit. The bin knows whether any
   phone has done so (the `AUDIO` box on the HW tab goes green).
2. **Trigger links.** Wi-Fi is the WebSocket the page already uses and is
   always on. Bluetooth and USB are optional extras, below.
3. **Clip library.** Upload MP3, AAC, OGG or WAV, up to 512 KB each. Clips
   are stored on the bin's flash under `/audio/` so every phone gets the same
   set, and each phone keeps a decoded copy in IndexedDB so it can still
   play them with no Wi-Fi at all. Names are lower-cased and cleaned:
   `Hi Chellam I Love u.wav` becomes `hi_chellam_i_love_u.wav`.
4. **What plays when.** One row per event, 31 of them: a person detected,
   a person gone, an object spotted, each command verdict, the emergency
   stop, every button, every mood change. Pick a clip from the dropdown;
   it saves immediately. **TEST** fires the real event through the bin so
   every connected phone plays it, exactly as it will during the demo.

The two clips in the repo's `audio/` folder ship in the filesystem image,
with *"Hi Chellam I love you"* assigned to **Human detected** and the AAC
one to **Phone connected**. Change them from the tab; nothing is hard-wired.

Events have a cooldown (1.5 s per event, 250 ms between any two) so a held
joystick does not produce a stutter of "obeyed". The emergency stop ignores
the cooldown. If no clip is assigned to an event, nothing is sent at all.

### The three links

| Link | What it carries | Where it works |
|---|---|---|
| **Wi-Fi** | Sound messages, commands, telemetry, the dashboard itself | Everywhere. Always on while the page is open. |
| **Bluetooth** | Sound messages, and the same JSON commands (the bin drives with Wi-Fi off) | Chrome on Android, ChromeOS, Windows, macOS. Not iOS. |
| **USB** | Sound messages on the serial port, JSON commands back | Web Serial on a laptop. WebUSB on Android with a CP2102 or CH340 board, via a small driver in `audio.js`. |

All three carry the same sequence number, so a phone on Wi-Fi and Bluetooth
at once plays each sound once. The Bluetooth payload is `seq;eventId;clip`
rather than JSON because a phone that never negotiated a bigger MTU only
sees the first 20 bytes, and that is enough to look the clip up locally.

**The catch, stated plainly:** Bluetooth, USB and the phone's own camera are
browser APIs that require a *secure* page, and `http://192.168.4.1` is not
one. Chrome will allow it if told to, once per device: open
`chrome://flags/#unsafely-treat-insecure-origin-as-secure`, enter the bin's
address, set **Enabled**, relaunch. The tab shows this exact instruction
when it applies. Wi-Fi needs none of it. The Bluetooth and USB links were
written against the documented Web Bluetooth, Web Serial and WebUSB APIs and
the CP210x/CH341 register maps; they have **not** been exercised on a phone
in this environment — the Wi-Fi link, the de-duplication and both message
formats have (see §10).

---

## 6. Vision: the phone is the eyes

No detector runs on the ESP32. It could not, and it does not pretend to. The
VISION tab runs **COCO-SSD under TensorFlow.js in the browser** — people
plus 80 everyday objects (cup, bottle, phone, banana, the usual) — on one of
two frame sources, and sends only the *result* to the bin:

| Source | How | Needs |
|---|---|---|
| **This device's camera** | `getUserMedia`, rear camera | The secure-page flag above (it is a camera API). |
| **ESP32-CAM snapshots** | Polls `http://trashcam.local/capture` a few times a second | The companion board in `firmware/DustECam/`, which joins the bin's AP and serves JPEGs with permissive CORS. No flag. |

Either way the model (~6 MB) comes from a CDN the first time and lives in the
browser cache after that. On the bin's own access point the phone has no
internet unless it keeps mobile data on, so **open the VISION tab once at
home** before the demo.

What the bin does with a report:

- A person **arriving** logs `HUMAN_DETECTED`, fires the `human_detected`
  sound, and cheers the personality up (happiness up, boredom down). A person
  standing there is not news. A person gone for 2.5 s logs `HUMAN_LOST`.
- An object it has not announced in the last 8 s logs `OBJECT_DETECTED cup`,
  fires `object_detected`, and confuses it slightly.
- A source that goes quiet for 5 s is dropped and the telemetry says so;
  stale numbers are never shown as current.
- Nothing here can move a motor. Detection is an input to the personality,
  like PLEASE and SORRY, and goes nowhere near the safety layer.

Reports can also arrive from a camera board directly: `POST /api/vision`
over Wi-Fi, or a text line on UART2 (`VISION persons=1 objects=cup conf=83`
at 115200 baud on GPIO 16 RX / 17 TX). The bin does not care who ran the
detector; it tells you the source in telemetry.

---

## 7. Decisions that differ from the brief

Each of these is a place where following the brief literally would have meant
either lying to the user or building something unsafe.

**1. STOP always stops.** The brief allows an angry bin to answer `NO.` to
STOP. It does — on screen. The motors stop anyway, every time. STOP is never
transformed, delayed or ignored. "It would not stop" is not a joke, it is a
fault report.

**2. Hold to drive.** A tap does not latch a direction. A robot that keeps
driving after you let go of the control is a hazard, and the dead-man's switch
is also what makes the delayed-command gag land honestly.

**3. PANIC does not move the motors by itself.** It is a mood and a light
show. Autonomous movement that the user did not ask for is the one kind of
surprise this project does not make.

**4. The battery readout says `NOT INSTRUMENTED`.** There is no divider on
this board, so there is no voltage to report. The brief's mock-up shows
`BATTERY 87%`; inventing that number would break the project's own rule about
never faking a sensor value.

**5. Nothing claims to be `DETECTED`.** The L298N and the motors are passive
and cannot be sensed on these pins, so the hardware page says `CONFIGURED` —
the firmware is driving those pins — and reserves `ONLINE` for states that are
genuinely observable, like the Wi-Fi link and the client count.

**6. There are two normal modes, on purpose.** The big green button is the
gag: it expires. The mode selector's `NORMAL` entry is a real, permanent
debug mode, because a machine this deliberately unreliable needs one honest
setting to debug against. The button lies; the settings do not.

---

**7. The phone is the speaker and the camera.** The brief wants the bin to
talk and to see. An ESP32 with an L298N can do neither, so both jobs go to
the phone that is already in the loop, and the hardware page says
`BORROWED FROM THE PHONE` rather than `CONFIGURED` for those two rows. What it
*does* report as its own is whether a phone is currently doing the job.

---

## 8. Calibration

**SETUP → MOTOR CALIBRATION.** Jog each motor forward and reverse; the jog
runs for at most two seconds and stops itself.

1. If a motor turns the wrong way, tick its **INVERT** (or swap its two `OUT`
   wires — equally valid).
2. **MIN DUTY** is the lowest duty that actually turns a loaded motor.
   Below it a DC motor buzzes and heats instead of moving, so any non-zero
   request is lifted to this value. Raise it until "slow" means slow rather
   than stalled.
3. **MAX DUTY** is the ceiling everything else is clamped to. Nothing the
   personality engine does can exceed it.
4. **ACCELERATION** is duty per 20 ms tick.
5. **STRAIGHTNESS TRIM** only ever takes power away from the faster side, so
   it cannot be used to exceed the ceiling.
6. **SAVE TO NVS** — settings survive a reflash.

---

## 9. Architecture

```
        PHONE / LAPTOP  (dashboard, speaker, detector)
          |  Wi-Fi WebSocket      ^  BLE notify / USB serial line
          v                      |
   +-------------------------+   |        ESP32-CAM (optional)
   |          ESP32          |   |        /capture JPEGs -> the phone
   |  webLayer   (AsyncTCP)  |   |
   |  bleLink / usbLink      |---+   same validate -> ring buffer path
   |  pipeline   (loop)      |   the command's journey
   |  personality            |   decides what to do instead
   |  vision                 |   what was seen, whether it is news
   |  soundBank              |   which clip, rate limited, one queue
   |  safety                 |   has the last word
   |  motors                 |   ramp, clamp, L298N
   +-----------+-------------+
               v
             L298N -> two motors
```

Every command takes exactly this path:

```
WEB BUTTON -> INPUT VALIDATION -> SAFETY CHECK -> PERSONALITY ENGINE
 -> COMMAND TRANSFORMATION -> OPTIONAL DELAY -> MOTOR CONTROLLER
 -> TELEMETRY -> WEB UI
```

| File | Contents |
|---|---|
| `DustEWeb.ino` | Wi-Fi, mDNS, and the loop that orders everything below. |
| `src/config/pins.h` | GPIO map. |
| `src/config/settings.h` | Every tunable number, plus the hardware inventory. |
| `src/core/types.h` | The vocabulary every module shares. |
| `src/core/prng.h` | The seeded xorshift32. The only randomness in the build. |
| `src/core/eventLog.*` | Ring buffer behind the on-screen log and the serial trace. |
| `src/motor/motors.*` | L298N, ramping, clamping, NVS calibration. |
| `src/safety/safety.*` | Latch, timeouts, and `enforce()`. |
| `src/personality/personality.*` | Traits, moods, the transformation table. |
| `src/command/pipeline.*` | The pipeline above, including the non-blocking delay. |
| `src/sound/soundBank.*` | The event catalogue, the event → clip map (JSON on LittleFS), cooldowns, the outbound queue. |
| `src/vision/vision.*` | Detection intake from WebSocket, HTTP and UART2; arrival/departure logic. |
| `src/net/webLayer.*` | HTTP, WebSocket, JSON, the audio API, the fallback page. |
| `src/net/bleLink.*` | NimBLE service: sound notifications out, JSON commands in. |
| `src/net/usbLink.*` | `SND {...}` lines out on the serial port, JSON lines in. |
| `data/` | The dashboard. Plain HTML/CSS/JS, no build step. `audio.js` is the speaker, `vision.js` the eyes. |
| `data/audio/` | Seed clips and `map.json`, packed into the filesystem image. |

Three tasks exist. The WebSocket callback (AsyncTCP task) and the BLE write
callback (NimBLE host task) are allowed to do three things only: reject
oversized frames, parse and validate JSON, and push a fixed-size struct into
a spinlocked ring. The audio upload handler additionally writes a file.
Everything that acts on a command happens in `loop()`. The emergency stop is
the single deliberate exception — it latches on arrival.

There is no `delay()` after `setup()` returns.

The WebSocket message format is documented in [PROTOCOL.md](PROTOCOL.md).

---

## 10. Verified how

`pio run` builds clean with `-Wall` (the only warning is inside NimBLE
itself) at 58 % of the 2 MB app partition and 20 % static RAM; the LittleFS
image packs with the seed clips. The dashboard was driven in headless Chrome
against a Python mock of this firmware's HTTP and WebSocket surface: page
load with no JS errors, the clip library and all 31 event rows, decoding of
the WAV and AAC seeds, unlock, a `sound` message playing the mapped clip, the
same sequence number arriving in BLE form being ignored, a truncated BLE
payload resolving through the map, the USB line form, the ping advertising
sound, a multipart upload with name sanitising, assignment, TEST through the
bin, delete with unassignment, and the VISION tab loading COCO-SSD and
reporting from a (fake) camera at ~4 detections/s. Not verified: any of it on
a real ESP32, a real phone's Bluetooth or USB, or a real ESP32-CAM.

---

## 11. Adding the hardware that is not there yet

The inventory flags at the bottom of `settings.h` are the seam:

```c
static const bool HW_LID_SERVO = false;
```

Flip one to `true` at the same time as you add its driver module and its pin
`#define`. The UI stops saying `NOT INSTALLED`, stops labelling that
subsystem `SIMULATED`, and starts showing it as `CONFIGURED`. Nothing else
has to change — the OPEN/CLOSE buttons, the event codes and the telemetry
fields already exist and already run through the personality engine.

Pins are reserved but deliberately not `#define`d in `pins.h`: an undefined
pin cannot be driven by accident.

### The body kit: eyes, speaker, hands

Three parts already have drivers. Each one has its own flag, and all three
default to on:

| Flag | Part | Pins | Module |
|---|---|---|---|
| `HW_EYES` | 2 × SSD1306 128×64 I²C OLED (left 0x3C, right 0x3D) | SDA 21, SCL 22 (split bus: right eye on 5/15) | `src/face/` |
| `HW_SPEAKER` | MAX98357A I²S amp + 4–8 Ω speaker | BCLK 14, LRC 32, DIN 4 | `src/sound/speaker.*` |
| `HW_HANDS` | 2 × SG90/MG90S servo | left 13, right 23 | `src/hands/` |

`src/body/` maps every sound event to an eye expression and a gesture. The
mood sets the resting face. The emergency stop shows crossed-out eyes and
parks the arms, then turns their pulses off. The eyes are probed over I²C and
show up as `ONLINE`/`MISSING` on the HW tab. The speaker and servos cannot be
detected, so set their flags to `false` if they are not fitted. On the HW
tab, the BODY card has test buttons for every gesture and expression.

The speaker plays `.wav` (PCM, or MP3 inside a WAV), `.mp3` and ADTS `.aac`.
The phone still plays anything else. Servos and the amp need their own 5 V
rail with a common ground. Never power them from the ESP32's 5 V pin.

The expression gallery, wiring diagram and upgrade list are in
[docs/dust-e-body-kit.html](../../docs/dust-e-body-kit.html).

---

## 12. When it does not work

| Symptom | Cause |
|---|---|
| Blank page, or a page saying "minimal" | `data/` was never uploaded. Run `pio run -t uploadfs`. |
| Clips vanished after a reflash | The partition table changed under them. `uploadfs` again, or re-upload from the tab. |
| No sound, `SOUND LOCKED` on the AUDIO tab | Nobody tapped ENABLE SOUND on that phone. Browsers insist. |
| A sound plays on one phone but not another | Each phone unlocks separately. The bin sends to all of them. |
| `CANNOT DECODE` next to a clip | That phone's browser cannot play the format. WAV and MP3 work everywhere; AAC nearly everywhere. |
| Bluetooth / USB button says `NEEDS SECURE PAGE` | The `chrome://flags` step in §5, once per device. |
| VISION says `could not start: camera needs a secure page` | Same flag, or use the ESP32-CAM source, which needs no flag. |
| VISION stuck at `MODEL downloading…` | No internet on the phone. Load it once at home; it caches. |
| `SNAPSHOT failed` with the ESP32-CAM source | Wrong URL, the cam is not on the same network, or its ribbon cable is loose (its serial log says). |
| `dust-e.local` does not resolve | Android does not do mDNS well. Use the IP from the serial port. |
| Connects, then `OFFLINE` every few seconds | Weak Wi-Fi. The link timeout is doing its job. Move closer or use the AP fallback. |
| Motors buzz but do not turn | `MIN DUTY` too low, or the motor supply is sagging. |
| Both motors run backwards | Two `INVERT` ticks, or swap both motors' `OUT` pairs. |
| It drives the wrong way on purpose | Working as designed. Check the event log — every transformation is logged with its reason. |
| It genuinely will not obey in `NORMAL` mode | That is a bug. `NORMAL` is the honest mode. Check the seed line and the log. |

The log is the diagnostic. `COMMAND_MODIFIED FORWARD -> BACKWARD (Because I
can.)` means the link is perfect and the bin is simply being difficult.

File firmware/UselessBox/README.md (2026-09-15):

# UselessBox

A standalone "useless box" module: a toggle switch that looks like a normal
button, but a servo arm reaches out and flips it back off. Unrelated to
DustE/DustERemote — this runs on its own tiny board and doesn't touch the
ESP-NOW protocol or the rest of this repo's firmware.

## Hardware

| | |
|---|---|
| Board | Digispark ATtiny85 ("Digispark (Default - 16.5MHz)") |
| Servo | Signal → P0, +5V → 5V, GND → GND |
| Switch | Wired across P2 (`SWITCH_PIN`, `INPUT_PULLUP`) and GND |
| Capacitor | Across 5V/GND at the servo — needed once you push more than 3 steps per 10 ms, or the board browns out and resets |

`P1` drives the onboard LED: flashes once at boot to show it's ready, then
lights solid once the box has been flipped 4+ times within 10 s of each other
("angry" mode).

`P3` (`SWITCH_OUT`) is driven low at boot and otherwise unused by the current
logic — reserved if you want to wire a second switch state out.

## Toolchain

Follow Digistump's Arduino IDE setup first:
<http://digistump.com/wiki/digispark/tutorials/connecting>

Library: `SoftRcPulseOut` (bit-banged servo pulses sized for the ATtiny85's
limited timers) — install via Library Manager or from
<https://github.com/simonrafferty/SoftRcPulseOut>.

## Behavior

- Flip the switch → `gotoPercent()` drives the servo from `POS_START` (180°,
  resting) to a target angle back toward `POS_END` (45°, hits the switch off)
  and back, in one of ten canned sequences (`Seq00`–`Seq09`).
- Fewer than 4 rapid flips in a row (each within 10 s of the last) → always
  the plain `Seq00` response.
- 4+ rapid flips → picks a harder-to-predict sequence. At boot, whatever the
  switch reads decides the mode for that session: switch **off** at power-up
  = sequential cycling through `Seq01`–`Seq09`; switch **on** = random
  (`randomSeed()` comes from the noise floor on the floating analog pin A5).
- `gotoPercent(targetPercent, steps, afterDelay)` is the only motion
  primitive: `steps` caps how far the servo moves per 10 ms tick (keep ≤3
  without the capacitor, up to ~11 with one), and `afterDelay` idles in place
  afterward while still refreshing the pulse so the servo doesn't hunt.

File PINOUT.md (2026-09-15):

# PINOUT

Exact GPIO assignments for both boards. These tables are the authority; they
match `firmware/DustE/src/config/pins.h` and
`firmware/DustERemote/src/config/pins.h` line for line. If you change a pin,
change it in the header **and** here.

---

## 1. Main controller — ESP32-S3-DevKitC-1

### 1.1 Pins you must not use

| GPIO | Why |
|---|---|
| 0 | Strapping pin (BOOT button). Pulling it low at reset enters download mode. |
| 3 | Strapping pin (JTAG source select). |
| 19, 20 | Native USB D− / D+. Using them kills USB-CDC serial and uploads. |
| 26–32 | SPI flash. Not brought out to the header on most boards for a reason. |
| 33–37 | Octal PSRAM on **N8R8 / N16R8** modules. Free on N8R2 (quad/no PSRAM). Assume they are taken unless you have checked your exact module. |
| 39–42 | JTAG. Usable, but you lose hardware debugging. |
| 43, 44 | UART0 TX/RX — the serial monitor. |
| 45, 46 | Strapping pins (boot mode / VSPI). |

Everything assigned below comes from the always-safe set:
**1, 2, 4–18, 21, 38, 47, 48**.

### 1.2 Assignments

| GPIO | Direction | Net | Connects to | Notes |
|---:|---|---|---|---|
| 2 | OUT | `NORMAL_LAMP` | MOSFET gate → lamp in the NORMAL MODE switch | Logic-level N-FET, lamp on the 5 V rail. Do **not** drive the lamp directly. |
| 4 | OUT (PWM) | `SERVO_LID` | MG996R signal | 50 Hz, 500–2500 µs. Servo power from the servo rail, **not** the ESP32. |
| 5 | OUT (PWM) | `SERVO_EYE_PAN` | SG90/MG90S signal | |
| 6 | OUT (PWM) | `SERVO_EYE_TILT` | SG90/MG90S signal | Omit if `USE_EYE_TILT 0`. |
| 7 | OUT (PWM) | `SERVO_FINGER` | SG90/MG90S signal | The finger. |
| 8 | I/O | `I2C_SDA` | VL53L0X ×2, SSD1306 | 4.7 kΩ pull-up to 3V3. Most breakouts already have one — do not stack four of them. |
| 9 | OUT | `I2C_SCL` | VL53L0X ×2, SSD1306 | 4.7 kΩ pull-up to 3V3. |
| 10 | IN pull-up | `LIMIT_CLOSED` | Lid closed microswitch → GND | Active LOW. Wire to the **NC-to-GND** contact so a broken wire reads "not closed" and faults safe. |
| 11 | IN pull-up | `LIMIT_OPEN` | Lid open microswitch → GND | Active LOW. |
| 12 | IN pull-up | `SWITCH_NORMAL` | NORMAL MODE latching switch → GND | Active LOW = ON. |
| 13 | IN pull-up | `HIDDEN_TRIGGER` | Concealed demo-rescue button → GND | Active LOW. See `DEMO.md` §5. |
| 14 | IN pull-up | `IR_THROAT` | IR break-beam receiver / proximity module OUT | Active LOW = blocked. Optional (`USE_IR_THROAT`). |
| 15 | OUT (PWM) | `SERVO_FINGER_DOOR` | SG90 signal | The hatch. |
| 16 | OUT | `LED_DATA` | WS2812B DIN | Through 330 Ω, as close to the first pixel as possible. |
| 17 | OUT | `I2S_BCLK` | MAX98357A BCLK | Shared with DFPlayer TX if `AUDIO_BACKEND = AUDIO_DFPLAYER`. |
| 18 | OUT | `I2S_LRCLK` | MAX98357A LRC | Shared with DFPlayer RX in the DFPlayer build. |
| 21 | OUT | `I2S_DOUT` | MAX98357A DIN | |
| 38 | OUT | `SERVO_POWER_EN` | P-FET gate driver / relay coil driver | **HIGH = servo rail live.** Firmware pulls it LOW on `Lid::emergencyStop()`. Defaults LOW at reset, which is the safe state. |
| 47 | OUT | `TOF_THROAT_XSHUT` | VL53L0X #1 XSHUT | Held LOW at boot, then released to re-address to 0x30. |
| 48 | OUT | `TOF_APPROACH_XSHUT` | VL53L0X #2 XSHUT | Released second, re-addressed to 0x31. |

### 1.3 I²C address map

| Address | Device | Set by |
|---|---|---|
| 0x29 | VL53L0X (factory default) | Transient only — both sensors are moved off it at boot. |
| 0x30 | VL53L0X — throat | `Sensors::begin()` |
| 0x31 | VL53L0X — approach | `Sensors::begin()` |
| 0x3C | SSD1306 OLED | Module solder jumper. If yours is 0x3D, change `OLED_ADDR` in `display.cpp`. |

The XSHUT sequencing matters: both sensors boot at 0x29, so they are held in
reset, brought up one at a time and re-addressed. If XSHUT is left floating
the second sensor will never be found, and `healthSummary()` reports
`PARTIAL`.

---

## 2. Remote — ESP32-C3 SuperMini

### 2.1 Pins you must treat carefully

| GPIO | Why |
|---|---|
| 2 | Strapping — must be HIGH at reset. **Left unused.** |
| 8 | Strapping — must be HIGH at reset. Used only for the onboard status LED (output, idles as the LED driver wants). |
| 9 | Strapping — LOW at reset enters download mode. Used as the SECRET button. Do not hold it while resetting. |
| 20, 21 | UART0 RX/TX. Free here **only because the build logs over native USB CDC** — you must set *USB CDC On Boot = Enabled*. |

### 2.2 Assignments

| GPIO | Direction | Function | Command sent |
|---:|---|---|---|
| 0 | IN pull-up | Button — UP | `CMD_UP` |
| 1 | IN pull-up | Button — DOWN | `CMD_DOWN` |
| 3 | IN pull-up | Button — LEFT | `CMD_LEFT` |
| 4 | IN (ADC1_CH4) | **Aux resistor ladder**, 8 buttons | see below |
| 5 | I/O | I²C SDA — OLED | — |
| 6 | OUT | I²C SCL — OLED | — |
| 7 | IN pull-up | Button — RIGHT | `CMD_RIGHT` |
| 8 | OUT | Onboard status LED (WS2812 on most boards) | — |
| 9 | IN pull-up | BOOT button — SECRET | `CMD_SECRET` |
| 10 | IN pull-up | Button — OK | `CMD_OK` |
| 20 | IN pull-up | Button — OPEN | `CMD_OPEN` |
| 21 | IN pull-up | Button — CLOSE | `CMD_CLOSE` |

### 2.3 Aux button ladder

Eight buttons on one ADC pin. 10 kΩ pull-up to 3V3; each button pulls the node
to GND through a different resistor.

```
3V3 ──[10k]──┬── GPIO4 (ADC1_CH4)
             ├──[   0R ]──o/o── GND   AI
             ├──[   1k ]──o/o── GND   ANGRY
             ├──[ 2.2k ]──o/o── GND   MOOD
             ├──[ 4.7k ]──o/o── GND   STOP
             ├──[  10k ]──o/o── GND   NORMAL
             ├──[  22k ]──o/o── GND   MUTE
             ├──[  47k ]──o/o── GND   LIGHT
             └──[ 100k ]──o/o── GND   DARK
```

| Button | R to GND | V at node | Expected ADC (12-bit, 11 dB) |
|---|---:|---:|---:|
| AI | 0 Ω | 0.00 V | ~40 |
| ANGRY | 1 kΩ | 0.30 V | ~372 |
| MOOD | 2.2 kΩ | 0.60 V | ~738 |
| STOP | 4.7 kΩ | 1.06 V | ~1309 |
| NORMAL | 10 kΩ | 1.65 V | ~2048 |
| MUTE | 22 kΩ | 2.27 V | ~2816 |
| LIGHT | 47 kΩ | 2.72 V | ~3377 |
| DARK | 100 kΩ | 3.00 V | ~3723 |
| *(none)* | ∞ | 3.30 V | ~4095 |

ADC1 on the C3 is not especially linear near the rails, so **measure your own
values**: set `CALIBRATE_LADDER 1` in `pins.h`, flash, open the serial
monitor, press each button, and paste the readings into `LADDER_CENTERS`.
`LADDER_WINDOW` (±140 counts) is the accept band around each centre; readings
between bands decode as "nothing pressed", which is also what you get when two
buttons are pressed at once.

---

## 3. Quick continuity checklist

Before first power-on, with the supply disconnected:

- [ ] No continuity between 5 V and GND anywhere.
- [ ] No continuity between 3V3 and GND.
- [ ] Every servo ground returns to the star ground point, not through the ESP32 board.
- [ ] SDA and SCL each read ~4.7 kΩ to 3V3 and open to GND.
- [ ] Both limit switches read open at rest and short to GND when pressed.
- [ ] GPIO38 gate driver holds the servo rail **off** with the ESP32 unpowered.

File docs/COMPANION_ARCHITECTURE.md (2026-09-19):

# COMPANION ARCHITECTURE

### Evolving the DUST-E into an autonomous companion without losing the plot

This document is the analysis and plan that comes before the code. It answers,
in order: what exists, what can be reused, what conflicts, what is missing,
and how the brain (Arduino UNO Q) and the body (ESP32) are split. Nothing in
the firmware or the pin maps has been changed by this document. Every change
it proposes is marked **PROPOSED** and needs a decision first.

The priority order is unchanged from the root README:

```
SAFETY → RELIABILITY → PHYSICAL COMEDY → MECHANICAL QUALITY
       → DEMO SPEED → VISUAL APPEAL → TECHNICAL COMPLEXITY
```

---

## 1. What is actually in the repository

The brief describes one robot. The repository contains **four separate
machines**, and the brief's feature list is a union of them. That is the single
most important finding. It is the root of every hardware conflict in §6.

| Machine | Path | Controller | Status in this repo |
|---|---|---|---|
| **DUST-E** | `firmware/DustE/` + `firmware/DustERemote/` | ESP32-S3 (+ ESP32-C3 remote) | Complete modular firmware. **Never compiled** (root README says so). Stationary: no motors. |
| **DustEWeb** | `firmware/DustEWeb/` (+ `DustECam/`) | Classic ESP32 (WROOM) | Builds clean under PlatformIO. **Never run on hardware.** Mobile: L298N + 2 DC motors, nothing else. |
| **UselessBox (UNO Q)** | `firmware/UselessBox/UselessBox_UnoQ/` | Arduino UNO Q (STM32U585 MCU side) | Newest file in the repo (2026-09-12). L298N, 3× HC-SR04, IR, buzzer, servo, switch, SSD1306. Uses blocking `delay()`. |
| Bench tests | `tests/l298n_motor_test/`, `tests/obstacle_avoid_test/` | Arduino UNO Q | Rewritten from ESP32 to UNO Q. L298N on **D5–D10**. |

Where each feature in the brief lives:

| Brief says the robot has | Where it actually exists |
|---|---|
| ESP32 control | DUST-E (**S3**) and DustEWeb (**classic**). These are different chips with incompatible pin maps. |
| L298N + two geared DC motors | DustEWeb (ESP32 GPIO 18/19/27/26/25/33) **and** UNO Q sketches (D5–D10). The UNO Q wiring is newer. |
| Servo eyeball | DUST-E `eye.*`: pan GPIO 5, tilt GPIO 6, eased, auto-detach |
| OLED face | DUST-E `display.*` (I²C 8/9) and UselessBox_UnoQ (`Wire2`, custom SSD1306 driver) |
| ToF proximity | DUST-E: 2× VL53L0X, **throat** (looks down into the bin) and **approach** (looks into the room) |
| Servo lid | DUST-E `lid.*`: MG996R, soft-close, limit switches, obstruction reversal |
| Mechanical finger | DUST-E `uselessFinger.*` (GPIO 7 + hatch GPIO 15); UselessBox (servo D11, switch D12) |
| WS2812B | DUST-E `leds.*`, GPIO 16 |
| MAX98357A + speaker | DUST-E `audio.*`: I²S 17/18/21, non-blocking WAV streaming from LittleFS |
| Personality engine | **Two different engines** (see §1.1) |
| Browser dashboard | DustEWeb only (`data/`: DRIVE, MIND, AUDIO, VISION, HW, SETUP tabs) |
| Browser-side computer vision | DustEWeb `data/vision.js`: COCO-SSD on TensorFlow.js, results sent to the ESP32 |
| ESP-NOW | DUST-E ↔ DustERemote |
| Safety layer | DUST-E: lid safety (hand detection, limit switches, servo power FET). DustEWeb: motor safety (latched E-stop, link/drive timeouts, ramp, duty ceiling). |
| Deliberate mistranslation | Both engines, with different weight tables |
| *(not in brief)* HC-SR04 ×3, IR, active buzzer | UselessBox_UnoQ |
| Microphone | **Nowhere** |
| Battery measurement | **Nowhere** (DustEWeb reports `NOT INSTRUMENTED` on purpose) |
| Wheel encoders, IMU, cliff sensors, bumpers | **Nowhere** |
| Camera | Optional ESP32-CAM snapshot server (`DustECam/`); phone camera |

### 1.1 The two personality engines

| | DUST-E `personality.*` | DustEWeb `personality.*` |
|---|---|---|
| State | 13 `PersonalityState`: IDLE, CURIOUS, ALERT, HAPPY, CONFUSED, ANGRY, SHY, SARCASTIC, SLEEPING, AI MODE, NORMAL MODE, USELESS MODE, ERROR | 9 `Mood`: NORMAL, HAPPY, BORED, CONFUSED, ANGRY, REBELLIOUS, SLEEPING, CHAOS, PANIC |
| Numbers | `anger` 0–100, `frustration` 0–12, interaction counters | 7 traits 0–100: anger, trust, happiness, confusion, boredom, obedience, rebellion (derived) |
| Policy axis | none | 9 `DriveMode`s selected by the user (NORMAL is a genuine debug mode) |
| Randomness | seeded xorshift32 | seeded xorshift32 (`core/prng.h`) |
| Owns hardware | no | no |

The brief's trait list comes from DustEWeb, and its mood list from DUST-E.
The companion needs **one** engine, so §15 proposes how to unify them.

---

## 2. Architecture map of what exists

```
DUST-E (ESP32-S3)                         DustEWeb (ESP32)
─────────────────────                       ────────────────────────────
loop(): sensors → lid → eye → finger        loop(): inbound queue → pipeline
        → leds → audio → display                    (validate → SAFETY → personality
        → remote → personality → behavior           → transform → delay) → personality tick
                                                    → vision tick → SAFETY.enforce
behaviorManager = the only module that              → motors.tick → sounds → telemetry
commands hardware (single audit point)
                                            webLayer (AsyncTCP) / bleLink / usbLink:
lid safety is local to lid.cpp:             validate + push to spinlocked ring only;
the behaviour layer is informed,            E-stop latches in the network task
not consulted

No delay() after setup() in either.         No delay() after setup() in either.
```

Both firmwares follow the same three rules the companion must keep:

1. **Safety is structurally upstream of personality.** It is not just a
   higher-priority `if`. The personality code has no path back into it.
2. **Nothing blocks.** Every actuator is a `millis()` state machine.
3. **It degrades instead of failing.** A dead sensor sets a flag, a missing clip
   is silent, and a lost link stops the motors.

---

## 3. Reuse: modules that carry over unchanged

| Module | From | Role in the companion |
|---|---|---|
| `hardware/eye.*` | DUST-E | Body. `lookNormalized(x, y)` is exactly the `LOOK_AT` primitive. |
| `hardware/lid.*` | DUST-E | Body. The safety logic is kept verbatim. |
| `hardware/uselessFinger.*` | DUST-E | Body. The NORMAL MODE gag survives (§15.4). |
| `hardware/leds.*` | DUST-E | Body. The pattern enum becomes the `LED_SET` vocabulary. |
| `hardware/audio.*` | DUST-E | Body. Prerecorded clips are the offline voice (§14). |
| `ui/display.*` | DUST-E | Body. `FaceExpression` + `say()` become `FACE_SET`. |
| `hardware/sensors.*` (`DebouncedInput`, ToF health) | DUST-E | Body. Extended with new range sensors. |
| `motor/motors.*` | DustEWeb | Body. Ramp, duty ceiling, min duty, trim, NVS calibration. |
| `safety/safety.*` | DustEWeb | Body. Latch + timeouts. The link becomes the UNO Q instead of a browser. |
| `core/prng.h`, `core/eventLog.*` | DustEWeb | Both sides. The Python port of xorshift32 matches bit for bit (`brain/dustebrain/prng.py`). |
| `data/` dashboard (HTML/CSS/JS, tab layout, style) | DustEWeb | Brain. Served from the UNO Q with new COMPANION and DEBUG tabs. |
| Event-log discipline (every decision logged with a reason) | Both | Both. |
| `tools/verify_project.py` | root | Extended to check the new pin map and protocol copies. |

## 4. Modules that must be modified

| Module | Change | Why |
|---|---|---|
| `personality.*` (both) | Unified, extended with `curiosity` and `social_energy`, moved to the brain (§15) | Its inputs (vision, speech, games) now originate on the UNO Q |
| DustEWeb `pipeline.*` | Mistranslation applies **only to human-issued manual commands**, never to navigation output | A mistranslated obstacle-avoidance turn is a collision, not a joke |
| DustEWeb `safety.*` | "Client" = the UNO Q link; adds obstacle, cliff, bumper, battery and physical E-stop inhibits; autonomous vs manual speed ceilings | Autonomy needs sensor-based inhibits, not only link-based ones |
| DUST-E `behaviorManager.*` | Split: hardware choreography stays on the body as named **gestures**; decisions move to the brain | The brief: "the ESP32 should not make high-level AI decisions" |
| DUST-E `pins.h` | Needs motor, bumper, battery and E-stop pins (§6.2) | The S3 map has one free GPIO left |
| DUST-E `remote.*` / DustERemote | Kept. On the mobile robot, remote **STOP always stops the motors** (it may still speed up the *eye*) | DustEWeb precedent: "It would not stop is not a joke, it is a fault report" |
| DustEWeb `vision.*` | Replaced on the body by the brain's world model; the phone/TF.js path stays as an optional input | The UNO Q camera is now the primary vision sensor |
| UselessBox_UnoQ | Not part of the companion. It stays as its own gadget; its `delay()`-based motion must never be copied into the body | Blocking delays |

## 5. New modules

**Brain (UNO Q, Linux, Python): `brain/`**

| Package | Responsibility | Phase |
|---|---|---|
| `dustebrain.vision` | camera grabber, detector, appearance signature, tracker, geometry, browser-viewable MJPEG stream (`stream.py`) | 1 |
| `dustebrain.world` | world model, person lifecycle, social zones, events, LLM summary | 1 |
| `dustebrain.sim` | deterministic synthetic scenarios (tests + DEBUG "simulate a person") | 1 |
| `dustebrain.body` | serial link, command validator, safety governor, telemetry | 2 |
| `dustebrain.nav` | navigation state machine, reactive avoidance, person approach, docking | 3 |
| `dustebrain.voice` | wake phrase, VAD, STT, TTS, audio routing, half-duplex policy | 4 |
| `dustebrain.mind.llm` | `LLMProvider` → `CloudLLM`, `LocalLLM`, `OfflineFallback` | 5 |
| `dustebrain.mind.conversation` | turn manager, output contract validation, memory | 5 |
| `dustebrain.mind.personality` | unified deterministic engine | 5 |
| `dustebrain.mind.social` | social decision system, cooldowns, target selection | 6 |
| `dustebrain.mind.games`, `.stories` | deterministic game/story engines (no LLM required) | 6 |
| `dustebrain.expression` | Emotion → PhysicalExpression mapping | 6–7 |
| `dustebrain.dashboard` | HTTP server, DRIVE + HW + DEBUG tabs (Phase 2, implemented); COMPANION tab and WebSocket push arrive with the phases that need them | 2 → 7 |

**Body (ESP32-S3): `firmware/BinBody/`**, assembled from the reused drivers
above plus:

| Module | Responsibility |
|---|---|
| `link/brainLink.*` | framed serial protocol, CRC, seq/ack, heartbeat |
| `motion/motion.*` | velocity commands with TTL, named motion primitives |
| `safety/reflex.*` | obstacle, cliff and bumper stops, E-stop input, battery cutoff. **Runs before `motion`.** |
| `gesture/gestures.*` | named servo choreographies (e.g. `NOD`, `SHAKE`, `EYE_WAVE`) with calibrated, clamped angles |
| `sensors/range.*` | front range array and cliff sensors |

---

## 6. Hardware conflicts

### 6.1 Conflicts that exist today

| # | Conflict | Consequence |
|---|---|---|
| C1 | **Two ESP32 families.** DUST-E uses GPIO 38/47/48, which do not exist on a classic ESP32. DustEWeb uses GPIO 25/26/27/33, which are SPI flash or PSRAM on an S3. | The two pin maps cannot be merged onto either chip as they stand. |
| C2 | **The L298N is documented in two places.** DustEWeb cites `tests/l298n_motor_test` as proof of its ESP32 wiring, but that test has since been rewritten for the UNO Q on D5–D10. | The repo does not say where the driver is physically wired today. |
| C3 | **The DUST-E S3 map is full.** Of the always-safe set (1, 2, 4–18, 21, 38, 47, 48), only GPIO 1 is free. The companion needs 6 motor pins plus bumpers, battery sense and an E-stop input. | Motors cannot be added without freeing pins or adding an expander. |
| C4 | **Audio is on the body; the voice is generated on the brain.** The MAX98357A hangs off the ESP32's I²S, but TTS runs on Linux. | Needs PCM streaming over the link, or a second audio output (§13). |
| C5 | **The UNO Q has one USB-C port.** Camera, microphone and ESP32 link all need USB. | A powered USB-C hub with PD pass-through is mandatory. |
| C6 | **HC-SR04 echo is 5 V; the UNO Q MCU and the ESP32 are 3.3 V.** `obstacle_avoid_test` already warns about this. | A divider or level shifter on every echo line. |
| C7 | **UNO Q `analogWrite()` misbehaves above ~4 PWM pins** (noted in `l298n_motor_test`). | Another reason not to keep motors plus servos on the UNO Q MCU. |
| C8 | **The "approach" VL53L0X is a single narrow cone** tuned for "person within 900 mm" at a stationary bin. | Not enough obstacle coverage for a moving base. |
| C9 | **DUST-E remote STOP is deliberately mistranslated** (it speeds things up). | Must never apply to wheels. |
| C10 | **Motor noise vs. microphone; motor current vs. the UNO Q supply.** | Listening while driving is unreliable; brownouts can reboot the brain mid-drive (the DustEWeb README already warns about this for the ESP32). |

### 6.2 DECIDED split: UNO Q = processing + sensors, XIAO ESP32-S3 = controllers

**Decision (2026-09-16):** the body controller is a **Seeed XIAO ESP32-S3**.
The UNO Q's Linux side does the processing. The UNO Q's own header pins, on its
STM32U585 MCU, carry the sensors, and the XIAO drives the actuators. Pin
assignments below are **PROPOSED**. They are written into firmware only after
the open questions at the end of this document are answered.

This replaces the full DUST-E ESP32-S3 map. The XIAO exposes only **11 GPIOs**
(D0–D10 = GPIO 1, 2, 3, 4, 5, 6, 43, 44, 7, 8, 9, all 3.3 V and **not
5 V tolerant**). The DUST-E map needs 20. The split below is what makes it fit.

```
               ┌──────────── UNO Q ────────────┐
 USB cam, mic ─┤ Linux (QRB2210): brain        │
               │   │ Bridge (RPC, on-board)    │
               │ MCU (STM32U585): sensor node  │── HC-SR04 ×3, IR, cliff ×2,
               │   │                           │   bumpers ×2, E-stop sense,
               └───┼───────────┬───────────────┘   OLED + INA219 (I²C), buzzer
                   │           │ USB CDC (via hub): commands, telemetry, TTS audio
     MOTION_OK ────┘           │
     (pulse train, 1 wire)     ▼
               ┌──────── XIAO ESP32-S3 ────────┐
               │ controller: final authority   │── L298N ─► 2 motors
               │ over anything that moves      │── PCA9685 (I²C) ─► servos
               │                               │── WS2812B, MAX98357A (I²S)
               └───────────────────────────────┘── VL53L0X throat (lid hand safety)
```

**Safety authority.** The XIAO is still the only thing that can energise a
motor, and it has the last word. The UNO Q MCU is a **safety sensor node**. It
never talks to the motors, but it can veto motion through one wire that Linux
cannot override:

- **MOTION_OK is a pulse train, not a level.** The MCU toggles the pin from its
  main loop (~50 Hz) only while its sensors are healthy and nothing is inside
  the stop distance: front obstacle, cliff, bumper, E-stop aux contact. The
  XIAO requires ≥ 2 edges in every 150 ms window. A steady HIGH, a steady LOW, a
  broken wire, a crashed MCU and a hung loop all look the same: no pulses, so
  no forward motion. It is toggled in software, **never with hardware PWM**,
  because a timer keeps running after the firmware hangs.
- **Escape.** While MOTION_OK is absent, the XIAO allows only reverse, at
  `ESCAPE_DUTY`, for at most `ESCAPE_MS` per event. All the sensors face forward
  or down-forward, so backing away is the only way out of a wall or an edge.
  Otherwise the robot would be stuck until someone picked it up.
- **The brain link** (USB heartbeat, command TTL) is checked independently by
  the XIAO, exactly as in §8.1.
- **The hardware E-stop** stays in series with the L298N motor supply and needs
  no computer at all.

#### XIAO ESP32-S3 (controllers)

Confirmed fitted (2026-09-17): **plain** XIAO ESP32-S3 (not Sense), **one lid
servo**, **12 WS2812B LEDs**, and a separate USB webcam on the UNO Q. No eye,
finger or hatch servo yet. With only one servo, the PCA9685 is **not needed
yet** and everything fits on the 11 pads directly.

| Pad | GPIO | Net | Notes |
|---|---:|---|---|
| D0 | 1 | `MOTOR_L_IN1` (PWM) | **10 kΩ pull-down.** L298N ENA jumper **on**. |
| D1 | 2 | `MOTOR_L_IN2` (PWM) | 10 kΩ pull-down |
| D2 | 3 | `LED_DATA` → WS2812B DIN (12 LEDs) | Strapping pin, but harmless on a high-impedance LED input. 330 Ω series. |
| D3 | 4 | `SERVO_LID` | 50 Hz. Servo power from the servo rail, never the XIAO. |
| D4 | 5 | `I2C_SDA` | VL53L0X throat @0x29 (lid hand safety), and the PCA9685 later. 4.7 kΩ pull-ups. |
| D5 | 6 | `I2C_SCL` | |
| D6 | 43 | *spare* | UART0 TX; reserved for `I2S_BCLK` (see below) |
| D7 | 44 | `MOTION_OK` ← UNO Q MCU D9 | Input. 100 kΩ pull-down so a missing wire reads "not OK". |
| D8 | 7 | `MOTOR_R_IN3` (PWM) | 10 kΩ pull-down. L298N ENB jumper **on**. |
| D9 | 8 | `MOTOR_R_IN4` (PWM) | 10 kΩ pull-down |
| D10 | 9 | *spare* | reserved for `I2S_DOUT` |
| USB-C | — | brain link to the UNO Q (through the hub) | Arduino: *USB CDC On Boot = Enabled* |

**Growth path, in the order the pins run out.** I²S needs three pins and only
two are spare, so adding the MAX98357A means adding the PCA9685 at the same
time and moving the lid servo (and any eye/finger servo) onto it, which frees
D3 for `I2S_LRCLK`. The alternative, if the amp never arrives, is a USB audio
adapter on the UNO Q — decided in Phase 4, not now. Either way the firmware
keeps a `HW_SPEAKER`-style inventory flag, as `DustEWeb/src/config/settings.h`
does today, so the dashboard says NOT INSTALLED instead of pretending.

**Why the L298N is driven on its IN pins with EN jumpered.** It needs 4 GPIOs
instead of 6: PWM on IN1 with IN2 low goes forward, the reverse goes backward,
and both low stops. Both low with EN high is a *brake*, not a coast, which is
acceptable at this speed. The pull-downs keep all four inputs low while the
XIAO is resetting, unpowered or flashing. The motor pins deliberately avoid
GPIO 43/44, which the boot ROM toggles.

**Servos move to a PCA9685** because there are no GPIOs left for them. One
I²C device gives 16 channels: eye pan, eye tilt, lid, finger and hatch, plus
spares. PCA9685 channel 15 is used as a logic output to drive the **servo-rail
MOSFET**, so the servo rail stays software-switchable.

#### UNO Q MCU header (sensors)

Existing assignments from `firmware/UselessBox/UselessBox_UnoQ` are **kept**.
Only the pins freed by moving the L298N and the servo change.

| Pin | Today | Proposed | Notes |
|---|---|---|---|
| D2 / D4 | HC-SR04 #1 TRIG / ECHO | **unchanged** | ECHO through a 5 V → 3.3 V divider |
| A0 / A1 | HC-SR04 #2 TRIG / ECHO | **unchanged** | divider |
| A2 / A3 | HC-SR04 #3 TRIG / ECHO | **unchanged** | divider |
| D3 | active buzzer | **unchanged** | |
| D12 | switch | **unchanged** → NORMAL MODE switch | |
| D13 | IR obstacle sensor | **unchanged** | |
| SDA/SCL (`Wire2`) | SSD1306 OLED | **unchanged**, + INA219 @0x40 for battery voltage and current | no free analog pin, so battery goes on I²C |
| D5 | L298N ENA | `BUMPER_L` | NC switch to GND, pull-up: a broken wire reads "hit" |
| D6 | L298N ENB | `BUMPER_R` | same |
| D7 | L298N IN1 | `CLIFF_L` | digital IR cliff sensor, fail-safe polarity |
| D8 | L298N IN2 | `CLIFF_R` | |
| D9 | L298N IN3 | `MOTION_OK` → XIAO D7 | software-toggled pulse train |
| D10 | L298N IN4 | `ESTOP_SENSE` | aux NC contact of the mushroom switch |
| D11 | servo | camera tilt servo | **fitted (19 Sep 2026):** up/down tilt for the USB webcam. `Servo.h` confirmed to compile against `arduino:zephyr:unoq` on this pin (`tests/cam_tilt_test/`); not yet flashed - the camera mount's real mechanical range is unconfirmed, so nothing has moved it yet |

**Consequence for the bench tests.** `tests/l298n_motor_test` and
`tests/obstacle_avoid_test` drive the L298N from the UNO Q. They stay in the
repo as a record of the bring-up, but they no longer match the wiring once the
driver moves to the XIAO. **Done (17 Sep 2026):** `tests/xiao_motor_test/`
replaces them for motor bring-up - same isolated-forward/reverse/together
sequence, on the XIAO's actual pins (matching `firmware/DustEBody/src/config/pins.h`
and `src/motor/motors.cpp`). Unlike the UNO Q sketches, it has a real
PlatformIO target and `pio run` in that folder actually builds (verified:
5.6% RAM, 7.8% flash, no warnings). The two superseded sketches now carry a
pointer comment at the top of each `main.ino` directing readers here.

**Why sensors on the MCU are acceptable here.** The HC-SR04 `pulseIn()` calls
block for up to 12 ms each. On the MCU that only delays the next sensor read,
never a motor update. On the XIAO it would stall motor ramping and audio
streaming, which is why they are not there.

---

## 7. Missing hardware

Only what the architecture actually needs, in the order it becomes necessary.

| Needed for | Part | Why it cannot be skipped |
|---|---|---|
| Phase 1 | USB webcam, wide FOV (≈ 70–100°), MJPEG | Primary vision sensor |
| Phase 1 | Powered USB-C hub with PD pass-through | C5 |
| Phase 2 | Physical E-stop (latching, in the motor supply) | §6.2; firmware-only E-stop is not enough for a moving robot |
| Phase 2 | Separate 5 V ≥ 3 A buck for the UNO Q + hub, star ground | C10 |
| Phase 2 | INA219 (I²C) on the UNO Q MCU's `Wire2` | `BATTERY_LOW` and the low-battery stop cannot be faked, and there is no free analog pin |
| Phase 2 | PCA9685 16-channel servo driver | The XIAO has no GPIOs left for servos (§6.2) |
| Phase 2 | 4× 10 kΩ pull-downs on the L298N IN pins, 100 kΩ on MOTION_OK, 5 V → 3.3 V dividers on every HC-SR04 ECHO | Safe state while any board is resetting or unpowered |
| Phase 3 (**before any autonomous roaming**) | 2× downward cliff sensors (VL53L0X or IR) | Stairs and table edges. Autonomy is **disabled in config** until `cliff_sensors: true`. |
| Phase 3 | Front bumper microswitches ×2 | Last-resort contact sensing that no software bug can mis-range |
| Phase 3 | 3 forward range sensors (VL53L1X preferred; the existing HC-SR04 ×3 work with level shifting) | C8 |
| Phase 3 | Wheel encoders + IMU (e.g. BNO055) | Turning by angle instead of by time, stall detection, dead reckoning for `RETURN_HOME` |
| Phase 3 | Printed AprilTag on the home base | Camera docking without SLAM |
| Phase 4 | USB microphone. A USB mic **array** (e.g. ReSpeaker class) is preferred. | There is no microphone. An array also gives speech direction for §27. |
| Phase 4 (option) | USB audio adapter + small amp | Only if PCM streaming to the MAX98357A (§13) proves unreliable |
| Later (optional) | 2D LiDAR (LD06 class) | Phase 4 mapping only. Not needed before then. |
| Later (optional, exploratory) | 3× omni wheel + 3× motor holonomic base (§11.6) | HTX Studio–style catch-the-throw mode. Replaces the L298N two-wheel drive; needs Phase 3's floor test passed first. |
| Optional | TB6612FNG / DRV8871 instead of the L298N | The L298N drops ~2 V and runs hot. It works, so it stays unless it limits speed control. |

---

## 8. Brain ↔ Body architecture

```
┌──────────────────────── UNO Q  (Linux, "brain") ─────────────────────────┐
│                                                                          │
│  vision ──► world model ──► social / nav planner ◄── mind (personality,  │
│   (proc)       (events)            │                  conversation, LLM, │
│                                    │                  games, memory)     │
│  voice (wake · VAD · STT · TTS) ───┤                        ▲            │
│                                    ▼                        │            │
│                           intent (structured JSON)          │            │
│                                    ▼                        │            │
│                         COMMAND VALIDATOR  (schema, enums, ranges, rate) │
│                                    ▼                                     │
│                         SAFETY GOVERNOR  (soft: social distance, speed   │
│                                    │      near people, follow limits,    │
│                                    │      autonomy enable, geofence)     │
│                                    ▼                                     │
│                         MOTION CONTROLLER (velocity + TTL, gestures)     │
│                                    │                                     │
│  dashboard (HTTP/WS) ──────────────┘ debug commands enter ABOVE the      │
│                                      validator, never below it           │
└────────────────────────────────────┬─────────────────────────────────────┘
          Bridge RPC (on-board)      │ USB CDC, framed, CRC, seq/ack, heartbeat
┌──────────────────────────┐         │
│ UNO Q MCU  (sensor node) │         │
│ HC-SR04 ×3, cliff, bump, │ MOTION_OK (pulse train, 1 wire)
│ E-stop sense, INA219,    │─────────┐
│ OLED face, buzzer        │         │
└──────────────────────────┘         │
┌────────────────────────────────────▼──── XIAO ESP32-S3  ("body") ─────────┐
│  brainLink ─► REFLEX SAFETY (hard: E-stop latch, link timeout, cmd TTL,   │
│               MOTION_OK veto + limited reverse escape, battery cutoff,    │
│               speed & accel ceilings) ─► motion ─► motors ─► L298N        │
│  gestures ─► PCA9685 servos: eye / lid (own hand-safety) / finger         │
│  leds (WS2812B) · audio (MAX98357A)                                       │
│  telemetry ─► brainLink                                                   │
└───────────────────────────────────────────────────────────────────────────┘
```

The OLED face and buzzer stay on the UNO Q MCU, where they are already wired
and working. The brain drives them over Bridge. Everything that moves is on the
XIAO.

**Two safety layers with different jobs.** The **governor** on the brain is
*social* safety: don't crowd people, slow down near them, stop following. It
can be wrong without anyone getting hurt. The **reflex** on the body is
*physical* safety: don't hit, don't fall, don't run away. Nothing the brain
sends can disable it. Its limits are compile-time ceilings plus NVS
calibration, and the link can only **lower** them.

### 8.1 Failsafe matrix

| Failure | Detected by | Result |
|---|---|---|
| UNO Q stops sending | ESP32: no heartbeat for `LINK_TIMEOUT_MS` (300 ms) | Motors hard stop; face shows `BRAIN LOST`; servos park; audio stops |
| UNO Q process crash / reboot | same | same. The ESP32 keeps running and waits for a fresh handshake before any motion. |
| Velocity command not refreshed | ESP32: command TTL (≤ 500 ms, capped on the body) | Target ramps to zero |
| ESP32 disconnects / resets | Brain: no telemetry for 300 ms | `body.available = false`; nav → `EMERGENCY_STOP`; the robot says *"I appear to have lost my legs."* |
| ESP32 boots | — | Motors stopped, servo rail off, autonomy disabled until the handshake + self-test pass |
| E-stop pressed (hardware) | power removed from the motors + ESP32 sense input | Latched; cleared only by the physical reset **and** an explicit `reset_estop` from the dashboard |
| LLM / STT / TTS / network down | Brain health monitor | `OfflineFallback` (§14). Motion safety is unaffected. |
| Camera down | Vision: no frame for 2 s | `vision.online = false`; the world model reports **unknown**, not "nobody"; autonomous approach disabled |
| Battery low / critical | INA219 on the UNO Q MCU | Low: brain → `RETURNING_HOME`. Critical: the MCU stops MOTION_OK pulses, so the body refuses forward motion. |
| UNO Q MCU hangs or crashes | XIAO: < 2 MOTION_OK edges in 150 ms | Forward motion blocked; reverse escape only; brain reports `SENSORS_LOST` |
| MOTION_OK wire broken / shorted | same (a steady level is not a pulse train) | same |
| Obstacle, cliff or bumper | UNO Q MCU → MOTION_OK stops | Forward motion blocked within ~150 ms, with no dependence on Linux |

---

## 9. Communication protocol (brain ↔ body)

**Implemented (body side, 17 Sep 2026):** `firmware/DustEBody/` - the XIAO
ESP32-S3 firmware: `brainLink` (this protocol), `reflex` (the rules in §8.1),
`motors` (L298N on four pins), `lid`, `leds`. It builds clean under PlatformIO
for `seeed_xiao_esp32s3`; it has not run on hardware. The Python reference in
`simbody.py` remains the specification. `tools/verify_project.py` now checks
that the firmware's safety constants and the brain's `body:` config block have
not drifted apart.

**Implemented (sensor node, 17 Sep 2026):** `firmware/DustESensorNode/` - the
UNO Q MCU's own sketch: the HC-SR04 fan, the IR throat sensor, and the
MOTION_OK pulse train the XIAO's reflex layer treats as its sensor veto. Cliff
sensors, bumpers, E-stop sense and the INA219 are wired into the sketch behind
`HW_*` flags and stay false until the parts in docs/COMPANION_BOM.md rows 1,
4, 8 and 9 are fitted. **Compiled and flashed on real hardware (19 Sep 2026)**
via `arduino-cli` against a physically connected UNO Q - see
firmware/DustESensorNode/README.md section 5 for the live `[sensor]` output
and the one real bug that first compile caught (`Serial.printf()` does not
exist on this core's `BridgeMonitor<>`, fixed by switching to `print()`
chains). PlatformIO still has no UNO Q target; `arduino-cli` does.

**Implemented (brain link, 17 Sep 2026):** `brain/dustebrain/body/link.py` -
`BodyLink`, the real client: every outbound command still passes through the
same `Validator`, and `SerialTransport` (pyserial) opens the actual USB link
once a XIAO exists to answer. `brain/tests/test_body_link.py` runs the whole
stack - encode, the wire, decode, `SimBody`, decode again - with no port and
no board, via an in-memory `LoopbackPipe`. `python -m dustebrain.apps.body_probe`
is the bring-up CLI for firmware/DustEBody/README.md section 6.

**Implemented (dashboard, 19 Sep 2026):** `brain/dustebrain/dashboard/` - the
DRIVE + HW + DEBUG web dashboard this phase's acceptance check names. A
stdlib-only `http.server` (no new dependency), polled from a small static
page rather than pushed over a WebSocket - simpler, and at 150 ms poll /
100 ms hold-to-drive resend it is still well under the command TTL. Every
command it sends is `src="manual"`, going through the same `BodyLink` and
Validator as `body_probe.py` - the dashboard can do nothing that CLI could
not already do. `python -m dustebrain.apps.dashboard --sim` runs it against
an in-process `SimBody` with no hardware at all, for exactly the same reason
`LoopbackPipe` exists; `--port COM5` runs it against a real body.
`brain/tests/test_dashboard.py` drives it over real HTTP against the real
`SimBody` reference (7 tests) and is what found the `manual_max_pct` gap
noted in section 9.2.

**Implemented (brain side, 17 Sep 2026):** `brain/dustebrain/body/protocol.py`
(framing, CRC, reader), `validator.py` (source policy, clamps, rate limits) and
`simbody.py` — a Python reference implementation of the body's reflex safety.
The failsafe matrix in §8.1 is tested against it in `brain/tests/test_simbody.py`.
The firmware is written to match that reference, not the other way round.
No serial port is opened yet.

**Transport:** USB CDC (ESP32-S3 native USB) through the powered hub,
`/dev/ttyACM*` on the UNO Q. One JSON object per line with a CRC suffix, so it
stays readable in a serial monitor, like DustEWeb's USB link:

```
{"v":1,"seq":1042,"t":583211,"type":"vel","l":35,"r":31,"ttl":300,"src":"nav"}*7A3F\n
```

`*XXXX` is CRC-16/CCITT-FALSE over the bytes between `{` and `}` inclusive.
Lines with a bad CRC are dropped and counted; they are never guessed at.

### 9.1 Envelope (every message)

| Field | Meaning |
|---|---|
| `v` | protocol version; a mismatch in `hello` refuses all motion |
| `seq` | per-sender monotonic u32 |
| `t` | sender's monotonic ms (latency and clock-skew diagnostics) |
| `type` | message type |
| `ack` | `true` = the receiver must reply with an `ack` |
| `src` | brain-side origin: `nav`, `social`, `llm`, `debug`, `manual`, `safety`. The body logs it; the brain's validator uses it for policy (e.g. `llm` may not send `vel`). |
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

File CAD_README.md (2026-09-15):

# CAD

All 24 custom parts, as parametric OpenSCAD.

Open <https://openscad.org/> — or render from the command line:

```bash
openscad -o lid_frame.stl -D 'part="lid_frame"' cad/lid_mechanism.scad
```

`cad/duste_params.scad` holds every shared dimension. Change a number there
and every part that references it follows. That is the entire point: the lid
width appears in the hinge, the servo mount, the linkage length and the body
cut-out, and they must not be allowed to disagree.

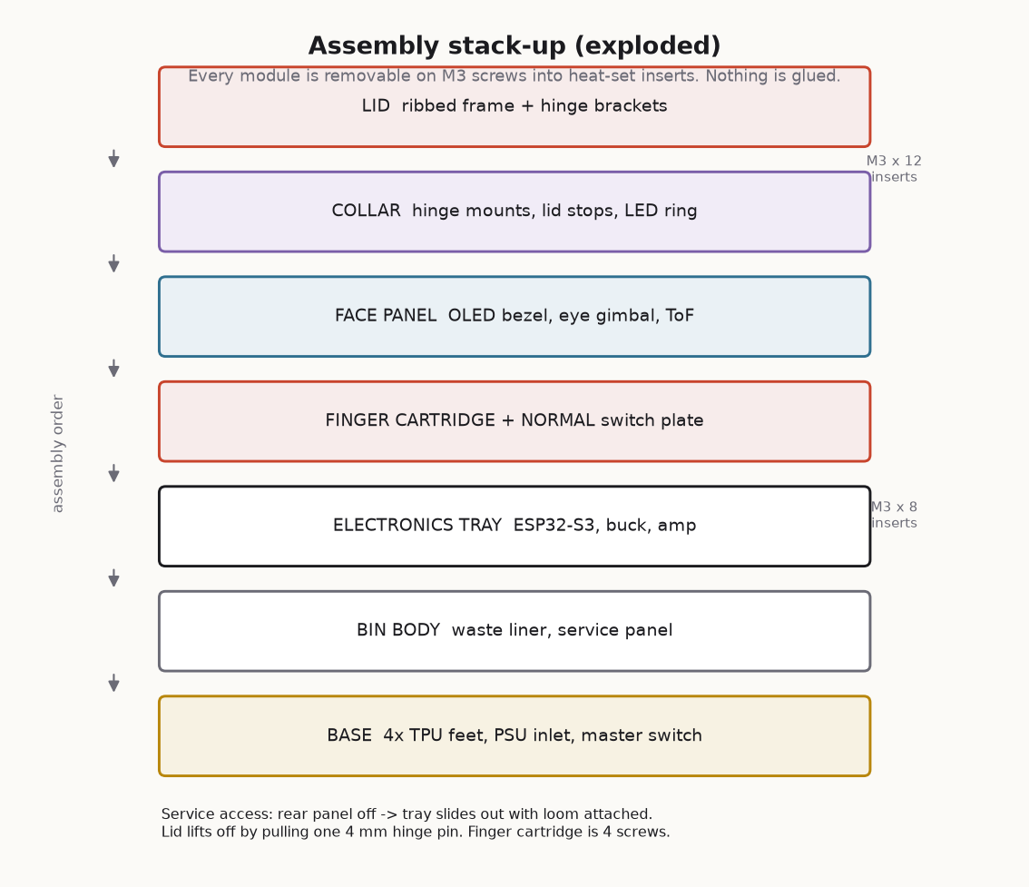
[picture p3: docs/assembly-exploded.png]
Exploded assembly


---

## 1. The torque budget

**Do this sum before you buy a servo. Do it again if you change the lid.**

```
tau_static = m · g · d · cos(theta)          worst case at theta = 0 (lid horizontal)

    m  = lid mass, including hinge hardware ........ 0.180 kg   ← WEIGH YOURS
    g  = 9.81 m/s²
    d  = hinge axis to centre of gravity ........... 0.110 m

tau_static = 0.180 × 9.81 × 0.110 = 0.194 N·m = 1.98 kgf·cm

required   = tau_static × safety factor (2.0) = 3.96 kgf·cm
fitted     = MG996R @ 5 V = 9.4 kgf·cm

margin     = 4.7 ×
```

The margin is generous on purpose. It covers a stiff hinge, a cold servo, a
sagging 5 V rail, and somebody resting a hand on the lid.

**If your lid is heavier**, recompute and move up: DS3218 is 20 kgf·cm, DS3225
is 25. **Do not fit an SG90** (1.8 kgf·cm) and hope. It will not lift the lid,
it will strip its own gears trying, and it will do so during the demo.

The ribbed `lid_frame` exists to keep `m` down. A solid 5 mm lid of the same
footprint is over 400 g, needs 4.4 kgf·cm static, and would push you to a
DS3218 and a bigger power supply for no benefit.

### Where the servo actually sits

The design uses a **two-bar linkage**, not a servo horn bolted to the hinge.
That puts the servo low in the body (better mass distribution, shorter power
run) and lets you trim the effective lever arm on assembly by moving the
linkage anchor. `link_len` is 62 mm nominal — expect to adjust it once. The
slotted holes in `servo_mount` exist for exactly this.

---

## 2. Part index
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

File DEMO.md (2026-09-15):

# DEMO SCRIPT

Two minutes. Four beats. One punchline.

The rule that governs everything below: **the audience must understand the
joke without your explanation.** If you have to narrate what the bin is doing,
the machine has failed, not the script. Talk less than you think you should.

---

## 1. Setup, before they arrive
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

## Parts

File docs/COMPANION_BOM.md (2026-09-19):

# COMPANION BOM

### What to buy to turn the bin into DUST-E, in the order it is needed

This is the shopping list for the companion upgrade only. The original
stationary build's parts are in [`BOM.csv`](../BOM.csv); this list does not
repeat them.

**Prices checked 17 September 2026.** Each row gives **two or three suppliers**
because half of these parts were out of stock at one shop and in stock at
another on the same day. Prices marked ✅ were read off the product page;
prices marked ~ are budget estimates and are flagged as such.
[Robu.in](https://robu.in/) blocks automated price checks, so its rows are
links only — often cheaper, worth comparing before you order. Nothing here is
an affiliate link. Indian prices include GST unless the shop says otherwise.

Rule for this list, the same one the firmware follows: **a part earns its place
by removing a failure, not by being interesting.**

---

## 0. Already on the bench — do not buy again

| Component | Notes |
|---|---|
| Arduino UNO Q (4 GB / 32 GB) | The brain. Linux side processes, MCU side reads sensors. |
| XIAO ESP32-S3 (plain, not Sense) | The body controller. Spare, if you ever need one: [Evelta ₹905](https://evelta.com/xiao-esp32-s3-2-4ghz-wifi-ble-5-0-8mb-psram-8mb-flash-dual-core/) *(out of stock)* · [Robocraze ₹1,089](https://robocraze.com/products/seeed-studio-xiao-esp32-s3-development-board-supports-wi-fi-bluetooth-5-0) *(sold out)* · [Robu](https://robu.in/product/seeed-studio-xiao-esp32s3-2-4ghz-wifi-ble-5-0/) |
| USB webcam | On the UNO Q. Phase 1 vision sensor. |
| L298N + 2 geared DC motors + chassis | Drive. The L298N is kept: it works. |
| Lid servo | The only servo fitted today. |
| WS2812B ×12 | On XIAO D2. |
| HC-SR04 ×3, IR module, buzzer, SSD1306 OLED, switch | Already wired to the UNO Q header. Staying there. |

---

## 1. Phase 2 — before the wheels turn under their own control

Nothing in this section is optional. Every row exists because a specific
failure is otherwise unhandled.

| # | Component | Spec that matters | Qty | ₹ each | Where to buy |
|---|---|---|---|---|---|
| 1 | **Emergency stop, 22 mm latching mushroom** | **Must have an NC contact** (1NO+1NC is ideal). The NC pair sits in series with the L298N motor supply; the spare contact tells the XIAO. | 1 | ✅ 93 | [Robocraze YWBL-WH ₹93](https://robocraze.com/products/ywbl-wh-mushroom-emergency-stop-push-button-switch-22mm) · [Robu LA38-11ZS (1NO+1NC)](https://robu.in/product/la38-11zs-mushroom-head-emergency-push-button-switch/) |
| 2 | **5 V 3 A switch-mode UBEC** | Powers the UNO Q + USB hub off the battery. **3 A continuous**, input 5.5–23 V. | 1 | ✅ 325 | [Robocraze ₹325](https://robocraze.com/products/5v-6v-3a-switch-mode-ubec) *(sold out)* · [Zbotic UBEC 5V/3A](https://zbotic.in/product/ubec-5v-3a/) · [Zbotic Hobbywing 5V 3A](https://zbotic.in/product/hobbywing-5v-3a-ubec/) · [QuartzComponents Bluesky mini](https://quartzcomponents.com/products/bluesky-mini-5v-3a-ubec-for-ptz-gimbals-and-rc-drones) |
| 3 | **XL4015 5 A buck module** | Second, separate rail for servo + LEDs, so a servo stall cannot brown out the brain. 1.25–36 V out, 5 A. | 1 | ✅ 112 | [Robocraze ₹112](https://robocraze.com/products/xl4015-dc-dc-step-down-adjustable-power-supply-module) *(in stock)* · [Robu XL4015](https://robu.in/?s=XL4015) |
| 4 | **INA219 I²C current/voltage monitor** | Battery telemetry on the UNO Q's `Wire2`. Without it, `BATTERY_LOW` would be a made-up number, which this project does not do. | 1 | ✅ 240 | [Robocraze 7Semi ₹240](https://robocraze.com/products/ina219-i2c-voltage-current-power-monitor-sensor-breakout-board-7semi) *(in stock)* · [Robu CJMCU-219](https://robu.in/product/cjmcu-219-ina219-i2c-interface-no-drift-bi-directional-current-power-monitoring-sensor-module/) |
| 5 | **Powered USB-C hub with PD pass-through** | The UNO Q has **one** USB-C port and must carry the webcam, the XIAO and later a microphone. PD pass-through keeps the board fed while they draw. | 1 | ~1,000–2,500 | [Amazon.in](https://www.amazon.in/s?k=powered+usb+c+hub+pd+passthrough) |
| 6 | **Resistor assortment** (need 10 kΩ ×4, 100 kΩ ×1, 330 Ω ×1, plus 1 kΩ/2 kΩ pairs for the HC-SR04 dividers) | The 10 kΩ pull-downs hold the L298N inputs low while the XIAO boots or is being flashed. Cheapest safety part in the build. | 1 kit | ✅ 95 | [Probots 150 pcs ₹95](https://probots.co.in/assorted-resistor-box-1-4-watt.html) *(in stock)* · [QuartzComponents combo](https://quartzcomponents.com/products/resistor-combo) · [Robocraze resistor box](https://robocraze.com/products/resistor-box) |
| 7 | Dupont + JST wire, screw terminals, heat-shrink | Star ground, and a loom that survives the tray sliding out. | — | ~300 | [Robocraze](https://robocraze.com/search?q=jumper+wire+jst) · [QuartzComponents](https://quartzcomponents.com/collections/wires-cables) |

**Battery — tell me what you are running** and I will size rows 2 and 3 and the
INA219 shunt properly. A 3S Li-ion pack (11.1 V) or a 12 V SLA both work: the
L298N wants 7–12 V at its motor terminal and the UBEC takes 5.5–23 V.

---

## 2. Phase 3 — before it is allowed to roam on its own

Autonomy stays disabled in config until rows 8 and 9 exist. That is enforced in
software, not left to discipline.

| # | Component | Spec that matters | Qty | ₹ each | Where to buy |
|---|---|---|---|---|---|
| 8 | **TCRT5000 IR reflectance module** | **Cliff sensors**, aimed at the floor ahead of each front wheel. Stairs and table edges. Digital out, trimmer for height. | 2 | ✅ 48 | [Robocraze ₹48](https://robocraze.com/products/tcrt5000-ir-sensor-module) *(in stock)* · [Robu](https://robu.in/product/tcrt5000-single-channel-line-tracking-sensor-module/) |
| 9 | **Micro limit switch, lever or roller** | **Bumpers.** Wired NC to ground, so a broken wire reads as "hit". The one sensor no software bug can mis-range. SPDT (1NO+1NC) is what you want. | 2 | ✅ 28 | [Robocraze roller ₹28](https://robocraze.com/products/micro-limit-switch-with-roller-for-cnc-reprap-prusa-3d-printers-5a-250vac) *(sold out)* · [Robocraze mini ₹8](https://robocraze.com/products/mini-limit-switch-5a-250v) *(sold out)* · [QuartzComponents SPDT roller](https://quartzcomponents.com/products/micro-switch-mini-roller) · [Probots roller](https://probots.co.in/micro-limit-switch-roller.html) · [Zbotic KW11-3Z](https://zbotic.in/product/tact-switch-kw11-3z-5a-250v-micro-switch-round-handle-3-pin-n-o-n-c-for-3d-printers-2pcs/) |
| 10 | **VL53L0X ToF module** | Throat sensor for the lid's hand safety, on the XIAO's I²C. | 1 | ✅ 289 | [Probots ₹289](https://probots.co.in/laser-range-finder-distance-sensor-time-of-flight-vl53l0x.html) *(in stock)* · [Robocraze ₹126](https://robocraze.com/products/vl53l0x-laser-ranging-sensor) *(sold out)* · [ThinkRobotics](https://thinkrobotics.com/products/vl53l0x-laser-ranging-sensor-time-of-flight-tof) · [Robu GY-530](https://robu.in/product/unsoldered-purple-gy-530-vl53l0x-time-of-flight-tof-laser-ranging-sensor-module/) |
| 11 | *(upgrade)* **VL53L1X ×3** | Replaces the HC-SR04 fan with 4 m ToF: no 5 V dividers, no acoustic crosstalk, far faster. Only if the HC-SR04s prove flaky. | 3 | link only | [QuartzComponents](https://quartzcomponents.com/products/nano-a000005) · [ThinkRobotics](https://thinkrobotics.com/products/vl53l1x-laser-ranging-sensor-time-of-flight-tof) · [Evelta 7Semi 4 m](https://evelta.com/evelta-vl53l1x-tof-distance-sensor-breakout-4-meter/) · [Robu Pimoroni](https://robu.in/product/pimoroni-vl53l1x-time-of-flight-tof-sensor-breakout/) |
| 12 | *(phase 3b)* **IMU + wheel encoders** | Turning by angle instead of by time, stall detection, dead reckoning for RETURN_HOME. | 1 + 2 | link only | [Robocraze MPU6050](https://robocraze.com/search?q=MPU6050) · [Probots encoders](https://probots.co.in/catalogsearch/result/?q=encoder) |
| 13 | AprilTag printed on paper | Camera docking without SLAM. | 1 | free | print it |

---

## 3. Phase 4 — voice

| # | Component | Spec that matters | Qty | ₹ each | Where to buy |
|---|---|---|---|---|---|
| 14 | **USB microphone** | There is no microphone anywhere in the build today. A **USB mic array** also gives speech direction, which the multi-person logic can use; a plain USB mic is fine for a first pass. | 1 | ~500–5,000 | [Amazon.in USB mic](https://www.amazon.in/s?k=usb+microphone) · [ReSpeaker mic array](https://robocraze.com/search?q=respeaker) |
| 15 | **MAX98357A I²S amplifier** | Only if the voice comes out of the robot's own body. **Needs row 17 too** — I²S wants three pins and the XIAO has two spare. | 1 | ✅ 269 | [Probots ₹269](https://probots.co.in/max98357-i2s-3w-class-d-amplifier-module-for-raspberry-pi-esp32.html) *(out of stock)* · [Robocraze ₹195](https://robocraze.com/products/smartelex-max98357a-i2s-audio-breakout-amplifier-for-raspberry-pi-and-microcontrollers) *(sold out)* · [QuartzComponents](https://quartzcomponents.com/products/max98357-3w-amplifier) · [Evelta Adafruit](https://evelta.com/i2s-3w-class-d-amplifier-breakout-max98357a/) |
| 16 | **Speaker, 4 Ω 3 W** | Matches the MAX98357A's 3.2 W at 4 Ω. A 40×70 mm rectangular driver fits a bin wall. | 1 | ✅ 249 | [Probots 4070 4 Ω 3 W ₹249](https://probots.co.in/rectangular-speaker-4070-4-ohm-3w-audio-driver.html) · [Probots 3-inch 4 Ω 5 W](https://probots.co.in/3-inch-full-range-audio-speaker-4-ohm-5w.html) |
| 17 | **PCA9685 16-channel servo driver** | Frees the XIAO pin the lid servo uses, and is what makes eye and finger servos possible later. Buy it **with** row 15, or when the second servo arrives — whichever comes first. | 1 | ✅ 499 | [Probots ₹499](https://probots.co.in/16-channel-servo-motor-driver-module-pca9685-for-arduino.html) *(in stock)* · [Robocraze soldered](https://robocraze.com/products/pca9685-16-channel-servo-motor-driversoldered) · [QuartzComponents](https://quartzcomponents.com/products/16-channel-12-bit-pwm-servo-driver-i2c-interface-pca9685-for-arduino-raspberry-pi) |
| — | *(alternative to 15–17)* USB audio adapter + small powered speaker | Plugs into the hub. No XIAO pins, no I²S timing, worse joke. | 1 | ~400 | [Amazon.in](https://www.amazon.in/s?k=usb+audio+adapter) |

---

## 4. Phase 5 — catch-the-throw base (HTX Studio–style, exploratory)

[HTX Studio](https://www.core77.com/posts/137907/HTX-Studio-Explores-the-Design-of-Smart-Roving-Trash-Cans)
built a fleet of mobile bins that use an onboard camera and a trained
detector to spot thrown rubbish in flight, predict where it will land, and
drive there in time to catch it — reported on by
[Hackaday](https://hackaday.com/2025/08/06/automated-rubbish-removal-system/),
[TechEBlog](https://www.techeblog.com/htx-studio-smart-trash-can-auto-aiming-robot/)
and [The Awesomer](https://theawesomer.com/robot-trash-can-catches-junk/777617/).
Each bin moves on **three motorised wheels** for fast omnidirectional
repositioning. HTX Studio is a content studio, not an open-hardware project —
**no schematic, firmware or BOM of theirs is published anywhere**, so nothing
below is sourced from their design. It is DUST-E's own parts list for
building the same *mechanism*, reusing what this repo already has.

Two things are missing before that mechanism is possible here:

1. **A holonomic drive base.** The L298N + 2 geared DC motors (§0) can turn
   or drive straight, but cannot translate sideways fast enough to get under
   a falling object. Three omni wheels 120° apart, each on its own motor,
   can move in any direction without turning first — this is the actual
   trick HTX Studio's bins use, not the ML.
2. **A trajectory predictor**, fed by the detector + tracker that already
   exist in `brain/dustebrain/vision/` (COMPANION_ARCHITECTURE.md §12).
   Fitting a parabola to an object's last few tracked positions and solving
   for where/when it lands is new code (`dustebrain.vision.trajectory`,
   not built yet); no new camera or model is needed for a first pass.

| # | Component | Spec that matters | Qty | ₹ each | Where to buy |
|---|---|---|---|---|---|
| 18 | **Omni wheel, 58 mm** | Servo-spline/Lego-NXT bore. 3 kg load rating at this size — check against the bin's weight before committing. | 3 | ✅ 445 | [Robokits RKI-1539 ₹445](https://robokits.co.in/robot-wheels/omni-wheels/omni-wheel-58mm-servo-lego-nxt-compatible) · [Robu (browse sizes)](https://robu.in/product-category/mechanical-parts-and-tools/robot-wheels/omni-wheels/) |
| 19 | **12 V DC geared motor, 6 mm D-shaft** | **Unverified fit for this bin's weight** — start with the cheap side-shaft motor for bench testing the base's geometry, but budget for the planetary one if it can't accelerate the bin fast enough. | 3 | ~325–1,199 | [Robokits RMCS-2275, 300 RPM, 1.8 kgcm ₹325](https://robokits.co.in/motors/dc-geared-motors/high-torque-side-shaft-dc-geared-motor-300rpm) *(cheap, likely underpowered)* · [Robokits Rhino IG32, 300 RPM, 20 kgcm ₹1,199](https://robokits.co.in/motors/rhino-ig32-12v-10w-dc-motors/dc-geared-ig-12v-motor/rhino-12v-dc-300rpm-20kgcm-ig32-heavy-duty-planetary-geared-motor) *(planetary, real torque)* |
| 20 | **TB6612FNG dual motor driver** | 2 boards give 4 channels; the base only needs 3. 3.3 V logic-native — no level shifting to the XIAO, unlike the L298N. | 2 | ✅ 209 | [Probots ₹209](https://probots.co.in/tb6612fng-dual-channel-dc-motor-driver-module.html) *(in stock)* · [Robokits RKI-4693 ₹284](https://robokits.co.in/motor-drives-drivers/dc-motor-driver/tb6612fng-ultra-small-dual-dc-motor-driver-module) · [Robocraze 7Semi](https://robocraze.com/products/7semi-tb6612fng-motor-driver-breakout-board) |
| 21 | **120° triangular base plate** | No off-the-shelf holonomic triangle plate turned up at any Indian supplier searched. Cut your own — the same OpenSCAD workflow `cad/` already uses for the other 24 printed parts. | 1 | — | design it, don't buy it |
| — | *(if the 3 wheels can't hold the bin's weight statically)* swivel support caster | Add a 4th, unpowered, centred caster; breaks true holonomic symmetry slightly but keeps the bin from tipping. | 1 | link only | [Robogears swivel caster](https://www.robogears.in/shop/3781246-universal-swivel-caster-wheel-1-inch-360-rotating-support-wheel-with-metal-top-plate-for-omnidirectional-robots-and-diy-chassis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) |

**Reused, not bought again:** the USB webcam and the UNO Q vision pipeline
(§0, COMPANION_ARCHITECTURE.md §12) are the only sensor this phase needs.

**This is a mechanical redesign, not an add-on.** It replaces the L298N
two-wheel drive (§0) with a three-motor holonomic base — the wiring in
COMPANION_ARCHITECTURE.md §6.2 (XIAO pins D0/D1/D8/D9 for the L298N) would
need to be redone for three motor channels instead of two.

**Sequencing, not a shortcut.** "Chase a falling object across the floor and
stop hard if something's in the way" is Phase 3's reactive-nav and reflex
layer, running faster and with a moving target instead of a fixed one. This
phase should sit **on top of** a Phase 3 that has already passed its floor
test (§17: 30 min roaming, 0 contacts) — not attempted before it. The
project's own priority order says why:

```
SAFETY → RELIABILITY → PHYSICAL COMEDY → MECHANICAL QUALITY → ...
```

Moving fast enough to catch something in the air is in direct tension with
that order. It's the reason this is filed as its own exploratory phase
instead of folded into Phase 2 or 3.

---

## 5. Budget

| Group | Priced rows | Still to estimate |
|---|---|---|
| **Phase 2** (must have) | 93 + 325 + 112 + 240 + 95 = **₹865** | USB-C hub ~₹1,000–2,500, wire ~₹300 |
| **Phase 3** (before roaming) | 96 (2× TCRT5000) + 56 (2× switch) + 289 = **₹441** | — |
| **Phase 4** (voice) | 269 + 249 + 499 = **₹1,017** | microphone ~₹500–5,000 |
| **Phase 5** (catch base, exploratory) | 3×445 (wheels) + 3×325 (cheap motors) + 2×209 = **₹2,743** | base plate (DIY), planetary motor upgrade adds up to 3×874 more |

**Everything that makes the robot safe costs about ₹580** — the E-stop, both
cliff sensors, both bumpers, the INA219 and the resistor kit. That is the
number worth quoting to anyone who asks why the parts list is this long.

---

## 6. Three things to get right when ordering

**The E-stop must have an NC contact.** A plain "latching push button" is not
the same part. The NC pair carries motor current and opens when the mushroom is
hit; the second contact is only a signal to the XIAO. A DPST unit rated for
mains is fine electrically — just confirm it is NC, not NO.

**"3 A" on a buck module usually means peak.** The LM2596 boards everywhere at
[₹48](https://robocraze.com/products/lm2596-dc-dc-buck-module) are rated 3 A
peak and sag well before that continuously. The UNO Q plus a hub plus a webcam
is a real 2–3 A load, and a brownout mid-drive is exactly the failure this
architecture exists to prevent. Use the UBEC or the XL4015 on that rail.

**Stock moves daily.** On the day of checking, the XIAO, the UBEC, the
MAX98357A, both limit switches and one VL53L0X listing were sold out at one
shop and available at another. Every row above has at least two suppliers for
that reason.

---

Sources: product pages at [Robocraze](https://robocraze.com/),
[Probots](https://probots.co.in/), [QuartzComponents](https://quartzcomponents.com/),
[Evelta](https://evelta.com/), [Zbotic](https://zbotic.in/) and
[ThinkRobotics](https://thinkrobotics.com/), read 17 September 2026;
[Robu.in](https://robu.in/) links are for price comparison and were not
machine-readable.

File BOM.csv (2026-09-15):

Category | Item | Qty | Preferred specification | Purpose | Alternative | Unit price USD | Line total USD | Where to look | Notes
Control | ESP32-S3 dev board | 1 | ESP32-S3-DevKitC-1, USB-C, N8R2 or N16R8 | Main controller | ESP32-S3-WROOM DevKit clone; ESP32-WROOM-32 (lose native USB) | 9.00 | 9.00 | https://www.google.com/search?q=ESP32-S3-DevKitC-1+N16R8 | N8R2 frees GPIO33-37. N16R8 has more PSRAM if you add a camera later.
Control | ESP32-C3 dev board | 1 | ESP32-C3 SuperMini, USB-C | Remote controller | ESP32-C3-DevKitM-1; any ESP32 board with 13 free GPIO | 4.00 | 4.00 | https://www.google.com/search?q=ESP32-C3+SuperMini | Pin map in PINOUT.md assumes the SuperMini pinout.
Actuator | High-torque servo | 1 | MG996R, metal gear, 9.4 kgf.cm @ 5V | Lid | DS3218 (20 kgf.cm) for a heavier lid; DS3225 | 5.50 | 5.50 | https://www.google.com/search?q=MG996R+servo | See the torque budget in CAD_README.md before substituting. Do not fit an SG90.
Actuator | Micro servo metal gear | 2 | MG90S, 2.2 kgf.cm | Eye pan and tilt | SG90 (plastic gear, shorter life) | 3.00 | 6.00 | https://www.google.com/search?q=MG90S+servo | Metal gear matters here - the eye moves constantly.
Actuator | Micro servo | 2 | SG90, 1.8 kgf.cm | Finger and hatch | MG90S for longer life | 2.00 | 4.00 | https://www.google.com/search?q=SG90+servo | The finger only has to flip a switch. Low torque is fine and safer.
Sensor | Time-of-flight sensor | 2 | VL53L0X breakout, I2C, XSHUT broken out | Throat detection and person detection | VL53L1X (longer range); HC-SR04 (cheaper, worse) | 4.50 | 9.00 | https://www.google.com/search?q=VL53L0X+breakout+XSHUT | XSHUT pin is REQUIRED - two sensors share address 0x29 at boot.
Sensor | IR break-beam pair | 1 | 3-pin IR obstacle module or a beam-break pair, 3.3V capable | Lid safety backup | Second VL53L0X; omit (set USE_IR_THROAT 0) | 2.50 | 2.50 | https://www.google.com/search?q=IR+break+beam+sensor+3.3V | Second independent channel for the hand-detect safety path.
Sensor | Microswitch SPDT | 2 | Lever microswitch, 5A, with roller or lever | Lid open and closed limits | Hall sensor + magnet (no contact wear) | 0.60 | 1.20 | https://www.google.com/search?q=SPDT+lever+microswitch | Wire COM-GND and NC-GPIO so a broken wire fails safe.
UI | OLED display | 2 | 0.96in SSD1306 128x64 I2C | Bin face and remote status | 1.3in SH1106 (change the driver); ST7789 TFT | 3.50 | 7.00 | https://www.google.com/search?q=0.96+SSD1306+OLED+I2C | One for the bin, one for the remote. Check the address (0x3C or 0x3D).
UI | WS2812B LED strip | 1 | 12 pixels, 5V, 60/m cut to length | Lighting and mood | WS2812B ring 12; any addressable 5V strip | 3.00 | 3.00 | https://www.google.com/search?q=WS2812B+strip+5V | 12 pixels at brightness 90 draws about 220 mA.
Audio | I2S amplifier | 1 | MAX98357A breakout, 3.2W mono | Audio | DFPlayer Mini + microSD (set AUDIO_BACKEND) | 4.50 | 4.50 | https://www.google.com/search?q=MAX98357A+I2S+amplifier | I2S build streams WAV from LittleFS - no SD card needed.
Audio | Speaker | 1 | 4 ohm 3W, 40-50 mm | Audio | 8 ohm 2W (quieter) | 2.50 | 2.50 | https://www.google.com/search?q=4+ohm+3W+speaker+40mm | Never ground either terminal - the amp output is bridge-tied.
Control input | Latching pushbutton | 1 | 19 mm illuminated latching, 1NO1NC + LED | NORMAL MODE switch | 12 mm toggle switch; any latching switch the finger can reach | 4.00 | 4.00 | https://www.google.com/search?q=19mm+illuminated+latching+pushbutton | Must LATCH - a momentary button gives the finger nothing to turn off.
Control input | Arcade button 16 mm | 7 | 16 mm momentary, screw mount | Remote D-pad OPEN CLOSE | 12 mm tactile with printed caps | 0.90 | 6.30 | https://www.google.com/search?q=16mm+arcade+button+momentary
Control input | Tactile switch 12 mm | 8 | 12x12 mm tactile with cap | Remote aux ladder | 6 mm tactile | 0.25 | 2.00 | https://www.google.com/search?q=12mm+tactile+switch+cap
Control input | Micro tactile switch | 1 | 6 mm tactile | Hidden demo trigger | Reed switch + magnet (fully concealed) | 0.20 | 0.20 | https://www.google.com/search?q=6mm+tactile+switch | Mount where the operator's hand naturally rests. See DEMO.md.
Power | PSU 5V 5A | 1 | 5V 5A 25W, barrel jack or screw terminal, CE/UL marked | Main supply | 5V 4A (tighter); 12V 5A + buck to 5V | 11.00 | 11.00 | https://www.google.com/search?q=5V+5A+power+supply+25W | Buy a marked supply from a real vendor. This one plugs into the wall.
Power | Buck converter | 1 | LM2596 or MP1584, 3A, adjustable | Logic rail if you feed 12V | Not needed on a 5V-only build | 1.50 | 1.50 | https://www.google.com/search?q=LM2596+buck+converter | Only required if your main supply is 12V.
Power | Master switch | 1 | DPST rocker, 10A, panel mount | Cuts actuator power | SPST 10A rocker | 1.50 | 1.50 | https://www.google.com/search?q=DPST+rocker+switch+10A | Must break the servo rail, not the logic rail.
Power | Fuse holder + fuse | 1 | Panel blade fuse holder + 5A blade fuse | Overcurrent protection | Polyfuse 4A hold | 1.20 | 1.20 | https://www.google.com/search?q=panel+mount+blade+fuse+holder
Power | P-channel MOSFET | 1 | IRF4905 or AO3401 (low current), TO-220 or SOT-23 | Servo rail soft cutoff | Automotive relay 5V 10A | 0.80 | 0.80 | https://www.google.com/search?q=IRF4905+P+channel+MOSFET | With a 2N7002 N-FET as the level shifter. Circuit in WIRING.md.
Power | N-channel MOSFET small signal | 2 | 2N7000 or 2N7002 | P-FET gate driver and lamp driver | BS170 | 0.20 | 0.40 | https://www.google.com/search?q=2N7000+MOSFET
Power | Electrolytic capacitor | 1 | 1000 uF 10V low-ESR | Servo rail bulk | 2x 470 uF in parallel | 0.50 | 0.50 | https://www.google.com/search?q=1000uF+10V+low+ESR+capacitor | The single most important part for avoiding brownout resets.
Power | Electrolytic capacitor | 2 | 470 uF 10V | LED rail and audio rail | 220 uF | 0.30 | 0.60 | https://www.google.com/search?q=470uF+10V+capacitor
Power | Ceramic capacitor | 10 | 100 nF 50V | Local decoupling | - | 0.05 | 0.50 | https://www.google.com/search?q=100nF+ceramic+capacitor
Passive | Resistor kit | 1 | 1/4W assortment incl. 330R 1k 2.2k 4.7k 10k 22k 47k 100k | LED data and remote ladder | Individual values | 3.00 | 3.00 | https://www.google.com/search?q=1/4W+resistor+assortment+kit | The remote ladder needs one each of 1k 2.2k 4.7k 10k 22k 47k 100k.
Interconnect | Terminal blocks | 4 | 5.08 mm screw terminal, 2-3 way, PCB mount | Power distribution | WAGO 221 lever nuts | 0.50 | 2.00 | https://www.google.com/search?q=5.08mm+PCB+screw+terminal
Interconnect | JST-XH connector kit | 1 | 2/3/4-pin with crimps and shells | Module connections | Dupont with locking shells | 8.00 | 8.00 | https://www.google.com/search?q=JST+XH+connector+kit+crimp | Locking shells - vibration walks bare Dupont off headers.
Interconnect | Silicone hookup wire | 1 | 22 AWG and 18 AWG, assorted colours | Wiring | PVC hookup wire | 9.00 | 9.00 | https://www.google.com/search?q=silicone+hookup+wire+22AWG+kit | 18-20 AWG for the servo rail, 22-26 AWG for signals.
Interconnect | Heat-shrink assortment | 1 | 2:1, 1.5-10 mm | Insulation | Electrical tape (worse) | 4.00 | 4.00 | https://www.google.com/search?q=heat+shrink+tubing+assortment
Interconnect | Perfboard | 1 | 70x90 mm double-sided | Power distribution and breakout | Custom PCB; solderable breadboard | 1.50 | 1.50 | https://www.google.com/search?q=70x90+perfboard+double+sided
Mechanical | Heat-set inserts M3 | 50 | M3 x 5.0 mm brass, knurled | Serviceable joints | M3 nuts in captive pockets | 0.12 | 6.00 | https://www.google.com/search?q=M3+heat+set+insert+5mm+brass | Needs a soldering iron with an insert tip - about 10 dollars extra.
Mechanical | Socket cap screws M3 | 1 | Assortment M3 x 6/8/10/12/16 mm | Assembly | Any M3 screws | 8.00 | 8.00 | https://www.google.com/search?q=M3+socket+cap+screw+assortment
Mechanical | Steel rod 4 mm | 1 | 4 mm x 200 mm ground rod, or a cut M4 screw | Hinge pin | M4 bolt with the thread turned down | 1.50 | 1.50 | https://www.google.com/search?q=4mm+steel+rod+200mm
Mechanical | Shoulder screws M3 | 2 | M3 x 8 mm shoulder, 4 mm shoulder dia | Linkage pivots | M3 screw + washer + nyloc | 0.80 | 1.60 | https://www.google.com/search?q=M3+shoulder+screw+8mm | A shoulder screw gives a proper bearing surface for the linkage.
Filament | PETG filament | 1 | 1 kg, structural parts | Body brackets tray finger | ABS/ASA if you have an enclosure | 22.00 | 22.00 | https://www.google.com/search?q=PETG+filament+1kg | PETG for anything that carries load or sees heat.
Filament | PLA filament | 1 | 1 kg, cosmetic parts | Panels lid skin remote shell | PETG throughout | 18.00 | 18.00 | https://www.google.com/search?q=PLA+filament+1kg | Cheaper and crisper for cosmetic surfaces.
Filament | TPU filament | 1 | 0.5 kg, 95A | Feet bumpers finger tip | Rubber feet bought in | 14.00 | 14.00 | https://www.google.com/search?q=TPU+95A+filament+500g | The soft finger tip and the lid stop pads come from here.
Optional | Camera module | 1 | OV2640 for ESP32-S3, 24-pin | Optional face and object tracking | Omit - the project must work without it | 6.00 | 0.00 | https://www.google.com/search?q=OV2640+ESP32-S3+camera | NOT in the base build. See README section on optional features.
Optional | Acrylic dome 26 mm | 1 | Clear half-dome or watch glass | Eye lens | Print eye_lens in clear PETG | 1.50 | 0.00 | https://www.google.com/search?q=26mm+clear+acrylic+dome | Printed lens works; a real dome looks better.
Optional | Li-ion cell + holder | 1 | 18650 2000 mAh + holder, or a small USB power bank | Remote power | USB power bank in the battery bay | 6.00 | 0.00 | https://www.google.com/search?q=18650+holder+battery | A power bank is simpler and has no charging circuit to get wrong.

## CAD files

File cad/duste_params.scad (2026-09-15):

// =============================================================================
//  duste_params.scad - shared parameters for every printed part.
//
//  Change a number here and every part that references it follows. This is
//  the whole reason the CAD is parametric: the lid width appears in the
//  hinge, the servo mount, the linkage length and the body cut-out, and
//  they must not disagree.
//
//  Units: millimetres. Printer assumptions: 0.4 mm nozzle, 0.2 mm layers.
// =============================================================================

// ---------------------------------------------------------------------------
// PRINT TOLERANCES
// Measured on a stock Ender-style printer. If your holes come out tight,
// raise fit_loose; if pins rattle, lower it. Do not scale whole parts.
// ---------------------------------------------------------------------------
fit_snug   = 0.15;   // press fit, e.g. a pin in a bracket
fit_loose  = 0.35;   // free rotation, e.g. hinge pin in its bore
fit_clear  = 0.60;   // panel in a slot, cable through a hole

$fn = 48;            // curve resolution; drop to 24 while iterating

// ---------------------------------------------------------------------------
// FASTENERS - M3 throughout, heat-set inserts everywhere a screw goes into
// plastic more than once.
// ---------------------------------------------------------------------------
m3_clear    = 3.4;    // through-hole for an M3 screw
m3_tap      = 2.9;    // self-tapping into plastic (single assembly only)
m3_head_d   = 6.2;    // socket-cap head diameter
m3_head_h   = 3.2;
m3_nut_af   = 5.6;    // across flats
m3_nut_h    = 2.6;

// Heat-set insert, M3 x 5.0 mm brass (the common "M3 short" size).
// Bore is deliberately UNDERSIZE - the insert melts its own interference.
insert_m3_d = 4.0;
insert_m3_h = 5.5;

// ---------------------------------------------------------------------------
// BIN BODY
// The reference build wraps a 210 mm square opening. If you are retrofitting
// a bought bin, measure YOUR opening and set these three numbers first.
// ---------------------------------------------------------------------------
bin_opening_x   = 210;
bin_opening_y   = 210;
bin_wall        = 3.0;    // wall thickness of the printed collar
bin_collar_h    = 26;     // how far the printed collar drops over the bin

// ---------------------------------------------------------------------------
// LID
//
//  TORQUE BUDGET - the sum that picks the servo. Redo it if you change
//  anything here; do not assume the reference servo still fits.
//
//     lid_mass_g        180 g   (printed lid + hinge hardware, weighed)
//     lid_cog_mm        110 mm  (hinge axis to centre of gravity)
//     tau_static = m*g*d = 0.180 * 9.81 * 0.110 = 0.194 N.m = 1.98 kgf.cm
//     required   = tau_static * safety_factor(2.0) = 3.96 kgf.cm
//     fitted     = MG996R at 5 V = 9.4 kgf.cm  ->  4.7x margin
//
//  The margin is generous on purpose: it covers a sticky hinge, a cold
//  servo, a sagging 5 V rail and someone resting a hand on the lid.
// ---------------------------------------------------------------------------
lid_x           = 214;
lid_y           = 214;
lid_t           = 3.0;    // top skin
lid_rib_h       = 8;      // stiffening ribs, keeps the lid light AND flat
lid_rib_t       = 2.4;
lid_mass_g      = 180;    // WEIGH YOUR LID and put the real number here
lid_cog_mm      = 110;
lid_safety_factor = 2.0;

lid_open_deg    = 84;     // mechanical travel; firmware uses 12..96 servo deg

// ---------------------------------------------------------------------------
// HINGE
// Two brackets, one 4 mm steel pin (a cut-down M4 screw or 4 mm rod).
// ---------------------------------------------------------------------------
hinge_pin_d     = 4.0;
hinge_boss_d    = 11;
hinge_bracket_t = 6;
hinge_span      = 150;    // centre-to-centre of the two brackets
hinge_offset_z  = 14;     // pin height above the collar top face

// ---------------------------------------------------------------------------
// SERVOS
// ---------------------------------------------------------------------------
// MG996R / DS3218 standard-size body
servo_std_x     = 40.5;
servo_std_y     = 20.0;
servo_std_z     = 38.0;
servo_std_tab_x = 54.0;   // across the mounting tabs
servo_std_tab_t = 2.6;
servo_std_hole_d= 4.2;    // tab holes, M4 or M3 with a washer
servo_std_shaft_off = 10.0; // tab face to output shaft centre

// SG90 / MG90S micro body
servo_micro_x     = 22.8;
servo_micro_y     = 12.4;
servo_micro_z     = 22.5;
servo_micro_tab_x = 32.2;
servo_micro_tab_t = 2.5;
servo_micro_hole_d= 2.3;  // M2 self-tapping
servo_micro_shaft_off = 5.9;

horn_screw_d    = 2.0;    // servo horn retaining screw

// ---------------------------------------------------------------------------
// LINKAGE
// Servo horn -> lid. A two-bar linkage, not a direct horn mount, so the
// servo sits low in the body and the lid gets a better lever arm.
// ---------------------------------------------------------------------------
link_len        = 62;     // hole centre to hole centre - TUNE ON ASSEMBLY
link_w          = 9;
link_t          = 4;
link_hole_d     = 3.2;    // rides on M3 shoulder screws
horn_arm_len    = 25;     // effective servo horn radius

// ---------------------------------------------------------------------------
// USELESS FINGER MODULE
// ---------------------------------------------------------------------------
finger_box_x    = 62;
finger_box_y    = 46;
finger_box_z    = 52;
finger_len      = 58;     // comically long on purpose
finger_w        = 14;
finger_t        = 6;
finger_tip_r    = 5;      // ROUNDED. No sharp edges anywhere near a user.
door_x          = 34;
door_y          = 22;
door_t          = 2.4;

// ---------------------------------------------------------------------------
// NORMAL MODE SWITCH
// A 19 mm latching pushbutton, or a 12 mm toggle. Set to match yours.
// ---------------------------------------------------------------------------
button_hole_d   = 19.2;   // 19 mm latching switch + clearance
button_plate_x  = 56;
button_plate_y  = 56;
button_plate_t  = 4;

// ---------------------------------------------------------------------------
// EYE
// ---------------------------------------------------------------------------
eye_ball_d      = 42;
eye_lens_d      = 26;     // acrylic dome or a printed clear disc
eye_pan_range   = 110;    // degrees, matches EYE_PAN_MIN..MAX in firmware

// ---------------------------------------------------------------------------
// SENSORS
// ---------------------------------------------------------------------------
vl53_pcb_x      = 25.4;   // Adafruit VL53L0X breakout
vl53_pcb_y      = 17.8;
vl53_hole_span  = 20.3;
vl53_hole_d     = 2.6;

oled_pcb_x      = 27.3;   // common 0.96" SSD1306 module
oled_pcb_y      = 27.8;
oled_win_x      = 22.0;
oled_win_y      = 11.5;
oled_hole_span_x= 23.5;
oled_hole_span_y= 23.8;

// ---------------------------------------------------------------------------
// ELECTRONICS TRAY
// ---------------------------------------------------------------------------
tray_x          = 150;
tray_y          = 110;
tray_z          = 4;
tray_wall       = 2.4;
tray_rail_w     = 6;      // slides out on rails; nothing is glued in

// ---------------------------------------------------------------------------
// REMOTE
// ---------------------------------------------------------------------------
remote_x        = 190;    // deliberately, absurdly oversized
remote_y        = 110;
remote_z        = 34;
remote_wall     = 2.4;
remote_btn_d    = 16;     // arcade-style 16 mm buttons
remote_antenna_d= 8;
remote_antenna_h= 120;    // does nothing. Essential.

// ---------------------------------------------------------------------------
// Shared helper modules
// ---------------------------------------------------------------------------

// Rounded box, used everywhere. Centred in X/Y, sitting on Z=0.
module rbox(x, y, z, r = 3) {
    hull() for (dx = [-1, 1], dy = [-1, 1])
        translate([dx * (x/2 - r), dy * (y/2 - r), 0])
            cylinder(r = r, h = z);
}

// Screw hole with a counterbore for the head.
module m3_cbore(depth, head_depth = m3_head_h) {
    cylinder(d = m3_clear, h = depth + 0.2, center = false);
    translate([0, 0, depth - head_depth])
        cylinder(d = m3_head_d, h = head_depth + 0.2);
}

// Heat-set insert boss. Print the bore undersize; the brass makes its own.
module insert_boss(h = insert_m3_h + 2, wall = 2.2) {
    difference() {
        cylinder(d = insert_m3_d + wall * 2, h = h);
        translate([0, 0, h - insert_m3_h])
            cylinder(d = insert_m3_d, h = insert_m3_h + 0.1);
    }
}

// A 45-degree chamfer ring, so top edges are not sharp.
module chamfer_ring(d, c = 1.2) {
    difference() {
        cylinder(d = d + 2, h = c);
        cylinder(d1 = d, d2 = d - c * 2, h = c + 0.1);
    }
}

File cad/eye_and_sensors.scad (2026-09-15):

// =============================================================================
//  eye_and_sensors.scad - the eyeball, its gimbal, and the sensor brackets.
//
//    part = "eye_ball"     x1 - hemisphere shell, takes the lens
//    part = "eye_lens"     x1 - print in clear PETG, or use a 26 mm acrylic dome
//    part = "eye_yoke"     x1 - tilt yoke, carries the ball
//    part = "eye_pan_base" x1 - pan servo mount, carries the yoke
//    part = "tof_bracket"  x2 - VL53L0X breakout bracket (throat + approach)
//    part = "oled_bezel"   x1 - SSD1306 frame, snaps into the front panel
//
//  The eye is the highest-value part of the whole build per gram of
//  filament: an audience reads "it is looking at me" long before it reads
//  any of the electronics. Print the ball in a matte colour and the lens
//  glossy - the contrast is what sells it.
// =============================================================================

include <duste_params.scad>

part = "all";

// ---------------------------------------------------------------------------
module eye_ball() {
    shell = 2.4;
    difference() {
        sphere(d = eye_ball_d);
        // hollow
        sphere(d = eye_ball_d - shell * 2);
        // flatten the back half - printable, and gives the yoke something
        // to grip
        translate([0, 0, -eye_ball_d]) cube(eye_ball_d * 2, center = true);
        // lens aperture, facing +X
        rotate([0, 90, 0])
            translate([0, 0, eye_ball_d/2 - 3])
                cylinder(d = eye_lens_d, h = 6);
        // lens seat lip
        rotate([0, 90, 0])
            translate([0, 0, eye_ball_d/2 - 4.6])
                cylinder(d = eye_lens_d + 3, h = 1.8);
    }
    // trunnions for the tilt axis
    for (dy = [-1, 1])
        translate([0, dy * (eye_ball_d/2 - 1), 0])
            rotate([90, 0, 0])
                cylinder(d = 5 - fit_loose, h = 5, center = true);
}

module eye_lens() {          // clear PETG, 3 perimeters, no infill
    difference() {
        union() {
            cylinder(d = eye_lens_d - fit_snug, h = 2);
            translate([0, 0, 2]) scale([1, 1, 0.45]) sphere(d = eye_lens_d - 2);
        }
        translate([0, 0, -0.1]) cylinder(d = eye_lens_d - 6, h = 1.2);
    }
}

// ---------------------------------------------------------------------------
module eye_yoke() {
    arm_h = eye_ball_d/2 + 6;
    difference() {
        union() {
            rbox(eye_ball_d + 14, 20, 5, 3);
            for (dy = [-1, 1])
                translate([-(eye_ball_d + 14)/2 + 4, dy * (eye_ball_d/2 + 2) - 2.5, 0])
                    cube([eye_ball_d + 6, 5, arm_h]);
        }
        // tilt bearing bores
        for (dy = [-1, 1])
            translate([0, dy * (eye_ball_d/2 + 2), arm_h - 4])
                rotate([90, 0, 0])
                    cylinder(d = 5 + fit_loose, h = 8, center = true);
        // tilt servo horn slot on one arm
        translate([-3, eye_ball_d/2 - 1, arm_h - 4])
            rotate([90, 0, 0]) cylinder(d = 8, h = 3);
        // pan servo shaft
        translate([0, 0, -0.1]) cylinder(d = 5.8, h = 5.2);
        translate([-4, -2.6, 3.4]) cube([20, 5.2, 1.8]);   // horn pocket
    }
}

module eye_pan_base() {
    difference() {
        union() {
            rbox(46, 34, 4, 3);
            // micro servo cradle standing up
            translate([-servo_micro_x/2 - 2, -servo_micro_y/2 - 2, 4])
                cube([servo_micro_x + 4, servo_micro_y + 4, servo_micro_z + 2]);
        }
        translate([-servo_micro_x/2, -servo_micro_y/2, 3.9])
            cube([servo_micro_x, servo_micro_y, servo_micro_z + 3]);
        for (dx = [-1, 1])
            translate([dx * servo_micro_tab_x/2, 0, 4 + servo_micro_z - 5])
                rotate([90, 0, 0])
                    cylinder(d = servo_micro_hole_d, h = 40, center = true);
        for (dx = [-1, 1])
            translate([dx * 19, 0, -0.1]) m3_cbore(4.2);
    }
}

// ---------------------------------------------------------------------------
// ToF BRACKET
// The throat sensor points straight down; the approach sensor points out at
// roughly chest height. Same bracket, mounted on different faces.
// The 4 mm standoff keeps the VL53L0X's cover glass clear of the plastic -
// a bracket that shadows the emitter is the single most common cause of
// "the sensor reads 8190 forever".
// ---------------------------------------------------------------------------
module tof_bracket() {
    difference() {
        union() {
            rbox(vl53_pcb_x + 10, vl53_pcb_y + 10, 3, 3);
            for (dx = [-1, 1])
                translate([dx * vl53_hole_span/2, 0, 3])
                    cylinder(d = 5.5, h = 4);
        }
        // sensor window - generous, do not let the print shadow the emitter
        translate([0, 0, -0.1]) rbox(vl53_pcb_x - 6, vl53_pcb_y - 6, 3.2, 2);
        for (dx = [-1, 1])
            translate([dx * vl53_hole_span/2, 0, 3 - 0.1])
                cylinder(d = vl53_hole_d, h = 4.2);
        for (dy = [-1, 1])
            translate([0, dy * (vl53_pcb_y/2 + 3), -0.1])
                cylinder(d = m3_clear, h = 3.2);
    }
}

// ---------------------------------------------------------------------------
module oled_bezel() {
    difference() {
        rbox(oled_pcb_x + 12, oled_pcb_y + 12, 4, 3);
        // viewing window
        translate([0, 3.5, -0.1]) rbox(oled_win_x + 1, oled_win_y + 1, 4.2, 1);
        // PCB recess from the back
        translate([0, 0, 4 - 2.0])
            rbox(oled_pcb_x + fit_clear, oled_pcb_y + fit_clear, 2.2, 1);
        for (dx = [-1, 1], dy = [-1, 1])
            translate([dx * oled_hole_span_x/2, dy * oled_hole_span_y/2, -0.1])
                cylinder(d = 2.4, h = 4.2);
    }
}

// ---------------------------------------------------------------------------
if (part == "eye_ball")          eye_ball();
else if (part == "eye_lens")     eye_lens();
else if (part == "eye_yoke")     eye_yoke();
else if (part == "eye_pan_base") eye_pan_base();
else if (part == "tof_bracket")  tof_bracket();
else if (part == "oled_bezel")   oled_bezel();
else {
    translate([  0,  0, 0]) eye_ball();
    translate([ 60,  0, 0]) eye_yoke();
    translate([130,  0, 0]) eye_pan_base();
    translate([  0, 70, 0]) tof_bracket();
    translate([ 60, 70, 0]) oled_bezel();
    translate([130, 70, 0]) eye_lens();
}

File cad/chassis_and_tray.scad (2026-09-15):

// =============================================================================
//  chassis_and_tray.scad - electronics tray, button housing, feet, panels.
//
//    part = "tray"          x1 - slide-out electronics tray
//    part = "tray_rails"    x2 - rails that the tray slides on
//    part = "button_plate"  x1 - NORMAL MODE switch mount
//    part = "service_panel" x1 - removable rear access panel
//    part = "foot"          x4 - TPU foot
//    part = "led_diffuser"  x1 - strip diffuser for the WS2812 ring
//    part = "speaker_grille"x1 - speaker cover
//
//  Serviceability rule for this whole project: nothing is glued and nothing
//  is buried. Every module comes out on M3 screws into heat-set inserts, and
//  the tray slides out of the back with the wiring still attached. At a
//  live demo you will be debugging this on a table with ten minutes to go,
//  and a bin you have to destroy to open is a bin you cannot fix.
// =============================================================================

include <duste_params.scad>

part = "all";

// ---------------------------------------------------------------------------
module tray() {
    difference() {
        union() {
            rbox(tray_x, tray_y, tray_z, 4);
            // low retaining lip
            difference() {
                rbox(tray_x, tray_y, tray_z + 8, 4);
                translate([0, 0, tray_z])
                    rbox(tray_x - tray_wall*2, tray_y - tray_wall*2, 10, 3);
            }
            // rail tongues
            for (dx = [-1, 1])
                translate([dx * (tray_x/2 + tray_rail_w/2 - 0.5) - tray_rail_w/2, -tray_y/2, 0])
                    cube([tray_rail_w, tray_y, 3]);
            // pull handle
            translate([0, -tray_y/2 - 6, 0]) rbox(40, 14, 6, 3);
        }

        // ESP32-S3 DevKitC-1 mounting pattern (nominal 25.4 x 52.1 hole span)
        for (dx = [-1, 1], dy = [-1, 1])
            translate([dx * 25.4/2 - 40, dy * 52.1/2, -0.1])
                cylinder(d = m3_tap, h = tray_z + 0.2);

        // Generic perfboard / buck / amp mounting grid, 10 mm pitch.
        // Drill what you need; the rest is ventilation.
        for (gx = [-2 : 4], gy = [-4 : 4])
            translate([gx * 15 + 15, gy * 11, -0.1])
                cylinder(d = 3.2, h = tray_z + 0.2);

        // cable pass-throughs
        for (dy = [-1, 1])
            translate([tray_x/2 - 12, dy * 30, -0.1])
                hull() for (dx = [0, 14]) translate([dx - 7, 0, 0])
                    cylinder(d = 10, h = tray_z + 0.2);

        // handle finger slot
        translate([0, -tray_y/2 - 6, 2]) rbox(28, 8, 6, 2);
    }
}

module tray_rails() {
    difference() {
        cube([12, tray_y + 10, 10]);
        // slot the tray tongue rides in
        translate([-0.1, -0.1, 3.5]) cube([tray_rail_w + fit_clear + 0.1, tray_y + 10.2, 3.4]);
        for (dy = [20, tray_y - 10])
            translate([8, dy, -0.1]) cylinder(d = m3_clear, h = 10.2);
    }
}

// ---------------------------------------------------------------------------
// BUTTON PLATE
// The NORMAL MODE switch and, critically, the geometry that puts it within
// reach of the finger. finger_reach below is the number to check on
// assembly: the switch face must sit inside the finger's arc.
// ---------------------------------------------------------------------------
finger_reach = finger_len + 6;    // tip travel from the hatch

module button_plate() {
    difference() {
        union() {
            rbox(button_plate_x, button_plate_y, button_plate_t, 5);
            // raised collar so the switch body is supported square
            cylinder(d = button_hole_d + 8, h = button_plate_t + 2);
        }
        translate([0, 0, -0.1])
            cylinder(d = button_hole_d, h = button_plate_t + 2.2);
        // anti-rotation notch found on most 19 mm latching switches
        translate([button_hole_d/2 - 0.6, -1.6, -0.1])
            cube([2.4, 3.2, button_plate_t + 2.2]);
        for (dx = [-1, 1], dy = [-1, 1])
            translate([dx * (button_plate_x/2 - 6), dy * (button_plate_y/2 - 6), -0.1])
                m3_cbore(button_plate_t + 0.2);
    }
    // Assembly aid: a witness mark showing where the finger tip should land.
    // Printed 0.4 mm proud - sand it off once you are happy with the reach.
    translate([0, 0, button_plate_t + 2])
        difference() {
            cylinder(d = button_hole_d + 6, h = 0.4);
            cylinder(d = button_hole_d + 4, h = 0.5);
        }
}

// ---------------------------------------------------------------------------
module service_panel() {
    difference() {
        rbox(160, 120, 3, 5);
        // ventilation slots - servos and the buck converter both like air
        for (gy = [-3 : 3])
            translate([0, gy * 14, -0.1])
                hull() for (dx = [-1, 1])
                    translate([dx * 55, 0, 0]) cylinder(d = 7, h = 3.2);
        for (dx = [-1, 1], dy = [-1, 1])
            translate([dx * 72, dy * 52, -0.1]) m3_cbore(3.2, 2.0);
        // USB-C service cut-out, so the board can be flashed without opening
        translate([-58, -52, -0.1]) cube([14, 10, 3.2]);
    }
}

// ---------------------------------------------------------------------------
module foot() {              // TPU, 30% infill - it should squash a little
    difference() {
        union() {
            cylinder(d1 = 34, d2 = 28, h = 10);
            translate([0, 0, 10]) cylinder(d = 20, h = 4);
        }
        translate([0, 0, 10 - 0.1]) cylinder(d = insert_m3_d + 0.4, h = 6);
        // concave underside, so it grips rather than skates
        translate([0, 0, -3]) scale([1, 1, 0.35]) sphere(d = 30);
    }
}

// ---------------------------------------------------------------------------
module led_diffuser() {
    len = 180; w = 14;
    difference() {
        union() {
            translate([-len/2, -w/2, 0]) cube([len, w, 3]);
            translate([-len/2, 0, 3]) rotate([0, 90, 0])
                cylinder(d = w, h = len);
        }
        // channel for a 10 mm WS2812 strip
        translate([-len/2 - 0.1, -5.5, -0.1]) cube([len + 0.2, 11, 3.2]);
        translate([-len/2 - 0.1, 0, 3]) rotate([0, 90, 0])
            cylinder(d = w - 2.6, h = len + 0.2);
    }
}

module speaker_grille() {
    difference() {
        cylinder(d = 52, h = 3);
        // ring = [radius, hole count]. Paired deliberately - a nested
        // for(r=..,n=..) in OpenSCAD is a cartesian product, not a zip.
        for (ring = [[8, 6], [16, 12]])
            for (i = [0 : ring[1] - 1])
                rotate([0, 0, i * 360/ring[1]])
                    translate([ring[0], 0, -0.1]) cylinder(d = 4, h = 3.2);
        cylinder(d = 5, h = 3.2);
        for (i = [0 : 3])
            rotate([0, 0, 45 + i * 90])
                translate([23, 0, -0.1]) cylinder(d = 2.6, h = 3.2);
    }
}

// ---------------------------------------------------------------------------
if (part == "tray")               tray();
else if (part == "tray_rails")    tray_rails();
else if (part == "button_plate")  button_plate();
else if (part == "service_panel") service_panel();
else if (part == "foot")          foot();
else if (part == "led_diffuser")  led_diffuser();
else if (part == "speaker_grille")speaker_grille();
else {
    translate([   0,    0, 0]) tray();
    translate([ 180,    0, 0]) tray_rails();
    translate([   0,  150, 0]) button_plate();
    translate([ 100,  150, 0]) foot();
    translate([ 200,  150, 0]) speaker_grille();
    translate([   0, -160, 0]) led_diffuser();
}

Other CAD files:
cad/finger_module.scad
cad/lid_mechanism.scad
cad/remote_enclosure.scad

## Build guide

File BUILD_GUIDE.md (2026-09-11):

# BUILD GUIDE

Assembly and calibration, in the order that works.

**Read §1 before you do anything else.** The single most common way to lose a
weekend on a build like this is to wire everything, flash it once, and then
debug five interacting faults simultaneously.

---

## 1. Build order

Each phase ends with a working, testable thing. Do not start the next phase
until the current one passes.

| Phase | Add | Test that it passes |
|---:|---|---|
| 1 | ESP32-S3 + lid servo on the bench | Servo sweeps 12°→96° smoothly, no buzz when parked |
| 2 | Both lid limit switches | `[hb]` shows the switch states changing as you move the lid by hand |
| 3 | Throat VL53L0X | `thr=` in the heartbeat tracks your hand |
| 4 | OLED | Boot screen, then the animated eye |
| 5 | WS2812B strip | Idle breathe, no flicker |
| 6 | Audio | `boot.wav` plays on reset |
| 7 | Finger cartridge (bench, unmounted) | Full hatch → pause → extend → retract cycle |
| 8 | Remote hardware | All 15 buttons print `[tx]` lines |
| 9 | ESP-NOW | `[remote] asked X -> doing Y` appears on the bin |
| 10 | Mistranslation | OPEN closes. Press it six times; compliance hits zero |
| 11 | Personality | Miss three times; the lines escalate |
| 12 | Integration | Full self-test passes, all subsystems `OK` |
| 13 | Final enclosure | Everything mounted, tray slides out, lid lifts off |

Phases 1–6 are all bench work on a breadboard. Do not mount anything in the
bin until phase 12 passes on the bench.

---

## 2. Before you start

**Tools:** soldering iron with a heat-set-insert tip, crimper for your chosen
connector, hex keys, digital calipers, a multimeter, and a bench supply with a
current limit if you have one.

**Print everything first.** `CAD_README.md` §4. The `lid_frame` is a ~9 hour
print — start it, then build the electronics while it runs.

**Install the heat-set inserts** into every printed part before assembly.
Iron at 220 °C, insert square, press until flush, let it cool before loading
it. Doing this after the part is mounted is miserable.

---

## 3. Electronics bring-up (bench)

### 3.1 Power first, and prove it

Wire the PSU → master switch → fuse → distribution bar → servo rail, with the
1000 µF bulk capacitor fitted. **Before connecting anything else:**

- [ ] Multimeter: no continuity 5 V ↔ GND
- [ ] Power on. Measure 5.0 V ±0.25 V at the servo rail
- [ ] Master switch off. Rail drops to 0 V
- [ ] GPIO38 driver: with the ESP32 unpowered, the servo rail is **off**

That last check is the important one. The safe state must be the default
state.

### 3.2 Then the logic

Power the ESP32-S3 from USB while you work — it isolates board faults from
rail faults. Only tie the two together once both are proven.

**Star ground.** Every ground returns to one bolt. Not daisy-chained, not
through the ESP32's ground pins. See `WIRING.md` §1, rule 2.

### 3.3 I²C

Bring the bus up with **one device at a time** and confirm each address:

```
0x3C  SSD1306
0x30  VL53L0X throat      (after XSHUT re-addressing)
0x31  VL53L0X approach
```

If the second ToF never appears, XSHUT is floating — that is the whole reason
GPIO47/48 exist. See `TROUBLESHOOTING.md` §3.

---

## 4. Lid assembly

1. Fit `hinge_body` ×2 to the collar; `hinge_lid` ×2 to the lid pads.
2. Slide the 4 mm pin through. **The lid must fall freely under its own
   weight** through the whole arc. If it binds anywhere, fix that now — a
   stiff hinge eats your entire torque margin and no amount of firmware will
   save it.
3. Mount `servo_mount` to the inside of the collar, screws finger-tight in
   the slots.
4. Fit the servo. **Do not fit the horn yet.**
5. Power up and let the firmware drive the servo to `LID_ANGLE_CLOSED` (12°).
6. *Now* fit the horn, at the angle that puts the lid on its closed stop.
7. Fit `linkage` between the horn and the lid anchor with M3 shoulder screws.
8. Fit `lid_stop` ×2 with their TPU pads at both ends of travel.

Step 5–6 ordering matters: fitting the horn while the servo is at an unknown
angle is how you end up with only 40° of usable travel.

### 4.1 Limit switches

Mount both microswitches so they are made **just before** the mechanical stop,
not at the same instant. The firmware wants the switch to confirm arrival
while the servo still has a degree or two in hand.

Wire **COM → GND, NC → GPIO**, so a severed wire reads as "not closed" and
faults safe.

---

## 5. Finger cartridge

Assemble and test this **on the bench, out of the bin**. It is much easier to
adjust in your hand.

1. Fit both micro servos to `servo_plate`.
2. Drive them to `DOOR_ANGLE_SHUT` (8°) and `FINGER_ANGLE_HOME` (18°), then
   fit the horns.
3. Fit `finger` to the extend servo; push the TPU `finger_tip` into its socket.
4. Fit `door` on its 2 mm pin, and link it to the door servo horn.
5. Run a full cycle. Watch for the finger fouling the hatch on the way out.

### 5.1 The reach check — do not skip this

Hold `button_plate` where it will be mounted. Run the cycle. **The finger tip
must land inside the printed witness ring**, and must overshoot the switch
face by roughly 6 mm so the switch is fully thrown.

- Tip lands short → move the button plate closer, or increase
  `FINGER_ANGLE_PRESS`.
- Tip lands long, servo strains → decrease `FINGER_ANGLE_PRESS`.
- Tip misses sideways → the cartridge is not square. Fix the mount, not the
  firmware.

Sand off the witness ring once you are happy.

---

## 6. Final assembly

Bottom-up, per the exploded diagram:

1. **Base** — TPU feet, PSU, master switch, fuse holder, IEC/barrel inlet.
2. **Body** — waste liner, `tray_rails`, then slide the tray in.
3. **Tray** — ESP32-S3, distribution perfboard, buck (if used), amp. All on
   screws. Nothing glued.
4. **Finger cartridge + button plate** — four screws, one connector.
5. **Face panel** — `oled_bezel`, eye assembly, both `tof_bracket`s, speaker
   grille.
6. **Collar** — hinge mounts, `lid_stop`s, LED strip in `led_diffuser`.
7. **Lid** — drop on, insert the hinge pin.
8. **Service panel** — last, so you can still get at everything.

Leave a **service loop** in the lid servo loom. The lid moves; the loom must
not be in tension at either end of travel.

---

## 7. Calibration

### 7.1 Lid endpoints — do this first

With the linkage fitted, in `settings.h`:

1. Set `LID_ANGLE_CLOSED` so the lid rests on its stop with the servo
   **not straining**. Listen: a servo holding against a hard stop hums. If it
   hums, back the angle off by 2° and reflash.
2. Set `LID_ANGLE_OPEN` so the lid is fully back but again not straining.
3. If the lid moves the wrong way, set `LID_INVERT = true`. Do not try to fix
   it by swapping the angles.
4. Confirm both limit switches assert at their endpoints. If
   `[lid] endpoint N not confirmed` appears, adjust the switch position, not
   the timeout.

Reference build: `LID_ANGLE_CLOSED 12`, `LID_ANGLE_OPEN 96`.

### 7.2 ToF thresholds

Watch the heartbeat and note the numbers for your geometry:

| Symbol | Set it to | Reference |
|---|---|---|
| `TOF_THROAT_OBJECT_MM` | comfortably above your empty-throat reading | 200 mm |
| `TOF_THROAT_CLEAR_MM` | 50–60 mm above `OBJECT_MM` (this gap is the hysteresis) | 260 mm |
| `SAFETY_HAND_MM` | far enough out that a hand is caught **before** the lid reaches it | 130 mm |
| `TOF_APPROACH_NEAR_MM` | where you want it to notice people | 900 mm |
| `TOF_APPROACH_FAR_MM` | 400–500 mm beyond NEAR | 1400 mm |

Test `SAFETY_HAND_MM` deliberately and repeatedly: put your hand in the
opening while the lid is closing. It must stop and reverse **every single
time**. See `TEST_PLAN.md` §2.

### 7.3 Eye endpoints

Drive the pan servo to its limits by hand-editing `EYE_PAN_MIN` / `MAX` until
the eye reaches the edges of its aperture without the yoke binding. Same for
tilt. Reference: pan 35–145, tilt 62–118.

### 7.4 Finger angles

Covered in §5.1. Reference: `DOOR_ANGLE_SHUT 8`, `DOOR_ANGLE_OPEN 92`,
`FINGER_ANGLE_HOME 18`, `FINGER_ANGLE_PRESS 112`.

### 7.5 Remote ladder

Set `CALIBRATE_LADDER 1` in the remote's `pins.h`, flash, open the serial
monitor, press each aux button, and paste the readings into `LADDER_CENTERS`.
Set it back to 0. Details in `PINOUT.md` §2.3.

### 7.6 Timing and feel

Once everything works mechanically, tune for comedy:

| Symbol | Default | Effect |
|---|---:|---|
| `LID_MS_CLOSE` | 900 | Lower = snappier, higher = more deliberate. Never below ~500. |
| `MISS_SILENCE_MS` | 2000 | The judgemental pause. **Leave it at 2000.** |
| `FINGER_PAUSE_MS` | 900 | The beat between the hatch opening and the finger appearing. This is the single most important number for the punchline. |
| `NORMAL_MODE_GRACE_MS` | 4500 | How long the bin behaves. Long enough to be convincing, short enough that the audience does not lose interest. |
| `THROW_WINDOW_MS` | 2600 | How long it waits before declaring a miss. |

---

## 8. First full power-on

- [ ] Bin on a stable surface, lid clear, hands clear
- [ ] Bench supply current-limited to 3 A if you have one
- [ ] Power on. Self-test runs: EYE, LEDS, AUDIO, LID, FINGER, SENSORS, REMOTE
- [ ] Any `FAIL` line — stop, fix, repeat. Do not carry on with a known fault
- [ ] `USELESSNESS 100%` appears
- [ ] Idle: eye drifts and blinks, LEDs breathe, lid still, servos silent
- [ ] Heartbeat every 5 s on serial, values sensible
- [ ] **Obstruction test** before letting anyone near it (`TEST_PLAN.md` §2)

Silence at idle is a real check, not a nicety — if you hear servo hunting, the
detach logic is not running, and you are wasting a few hundred mA and
shortening the servos' life.

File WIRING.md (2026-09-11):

# WIRING

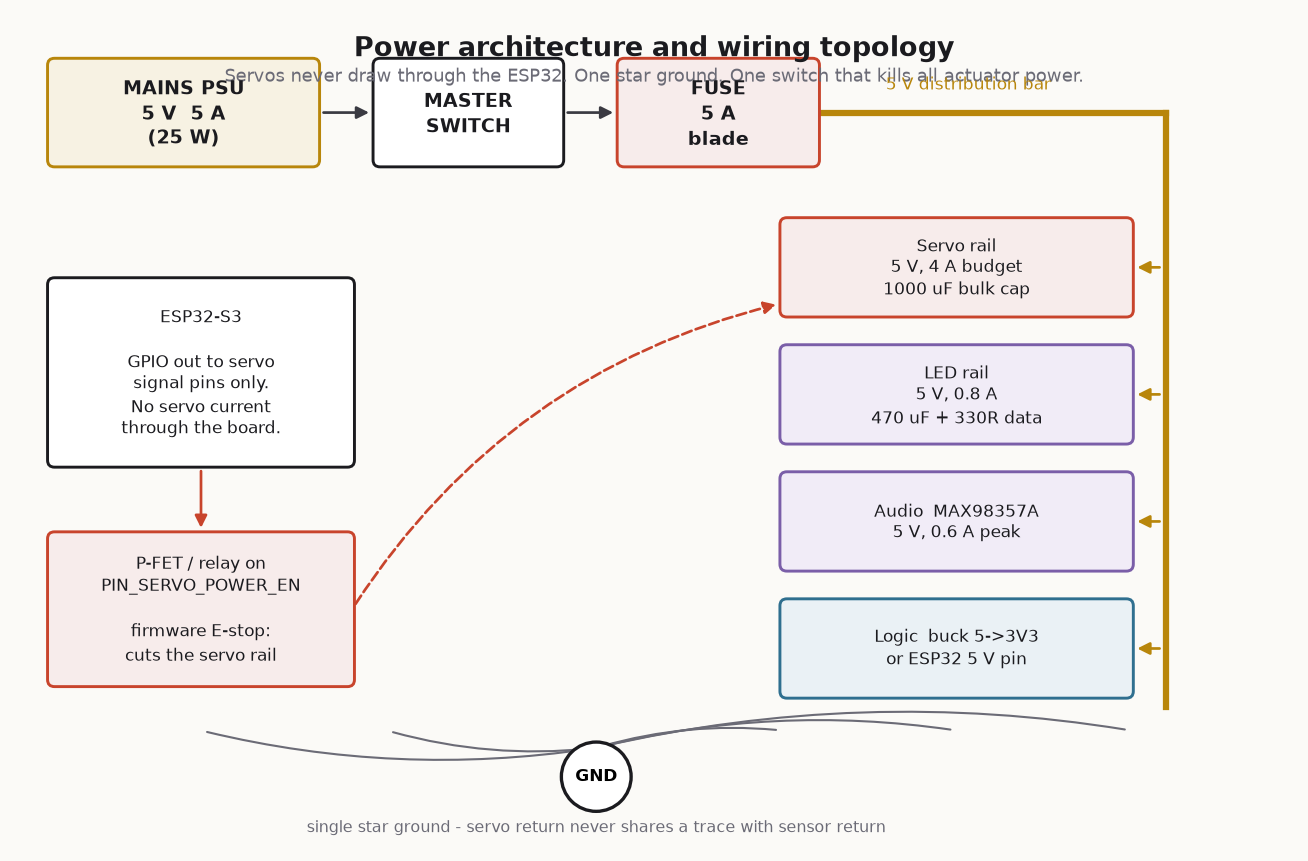
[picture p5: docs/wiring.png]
Power architecture


Complete connection table, power budget and the three wiring rules that
account for most of the failures people hit on this kind of build.

---

## 1. The three rules

**1. Servos never draw current through the ESP32.**
The dev board's 5 V pin is fed through a diode and a narrow trace. An MG996R
stalls at 2.5 A. Give the servos their own rail straight from the PSU.

**2. One star ground.**
Servo return current is spiky and large. If it shares a wire with the ToF
sensors' ground, the resulting few hundred millivolts of ground bounce shows
up as phantom range readings. All grounds meet at one bolt/bar, and only there.

**3. The master switch cuts actuator power, not logic.**
When something jams you want the motors dead and the display still telling you
why. The master switch and the GPIO38 soft-cutoff both act on the servo rail.

---

## 2. Power budget

Measured/datasheet worst case, main controller:

| Load | Qty | Idle | Moving | Stall / peak |
|---|---:|---:|---:|---:|
| MG996R — lid | 1 | 10 mA (detached) | 500–900 mA | 2500 mA |
| MG90S — eye pan | 1 | 5 mA | 150 mA | 700 mA |
| MG90S — eye tilt | 1 | 5 mA | 150 mA | 700 mA |
| SG90 — finger | 1 | 5 mA | 130 mA | 650 mA |
| SG90 — hatch | 1 | 5 mA | 130 mA | 650 mA |
| WS2812B ×12 | 12 | — | 220 mA @ brightness 90 | 720 mA all-white |
| MAX98357A + 4 Ω | 1 | 3 mA | 300 mA | 900 mA transient |
| ESP32-S3 + sensors + OLED | — | 90 mA | 240 mA (Wi-Fi TX) | 500 mA |

**Realistic simultaneous worst case** — lid moving, eye tracking, LEDs on,
audio playing: roughly **2.4 A**.
**Absolute worst case** with every servo stalled: about **6.5 A**, which the
firmware never commands and the mechanical stops prevent.

Specify a **5 V 5 A (25 W)** supply. That gives 2× headroom on the realistic
case and rides out the stall transients on the bulk capacitance.

> The firmware detaches idle servos (`LID_IDLE_DETACH_MS`, `EYE_IDLE_DETACH_MS`),
> so between interactions the whole machine sits at roughly 350 mA. This is
> also why the bin is silent when idle — a parked-but-attached analogue servo
> hunts and buzzes.

---

## 3. Power distribution

```
      ┌──────────────┐
      │  5 V / 5 A   │
      │   PSU        │
      └──────┬───────┘
             │  2.5 mm² / 14 AWG
      ┌──────┴───────┐
      │ MASTER SWITCH│   (DPST, 10 A — breaks 5 V to actuators)
      └──────┬───────┘
             │
      ┌──────┴───────┐
      │  FUSE 5 A    │   blade fuse in a panel holder
      └──────┬───────┘
             │
      ╞══════╪══════════════════════════════╡  5 V distribution bar
             │
   ┌─────────┼──────────┬─────────────┬──────────────┐
   │         │          │             │              │
   ▼         ▼          ▼             ▼              ▼
SERVO      LED        AUDIO        LOGIC          spare
RAIL       RAIL       RAIL         RAIL
(via       470 µF     220 µF       ESP32 5V pin
 P-FET)    + 330R                  or buck to 3V3
1000 µF    on data
```

### Decoupling — do not skip this

| Where | Part | Why |
|---|---|---|
| Servo rail, at the distribution point | 1000 µF, 10 V electrolytic, low-ESR | Absorbs servo inrush. Without it the ESP32 browns out the first time the lid moves. |
| Servo rail, at each servo connector | 100 nF ceramic | Local HF decoupling. |
| LED rail, at the first pixel | 470 µF, 10 V | WS2812 strips draw in sharp steps. |
| LED data line | 330 Ω series | Damps reflections, protects the first pixel's input. |
| Audio rail | 220 µF + 100 nF | MAX98357A pulls hard on bass transients. |
| ESP32 3V3, near the module | 10 µF + 100 nF | |

---

## 4. Connection table — main controller

### 4.1 Servos (5 pin-headers, JST-style or 0.1" 3-pin)

| Servo | Signal → GPIO | + | − |
|---|---|---|---|
| Lid (MG996R) | 4 | Servo rail 5 V | Star GND |
| Eye pan (MG90S) | 5 | Servo rail 5 V | Star GND |
| Eye tilt (MG90S) | 6 | Servo rail 5 V | Star GND |
| Finger (SG90) | 7 | Servo rail 5 V | Star GND |
| Hatch (SG90) | 15 | Servo rail 5 V | Star GND |

Signal wires carry only a few mA — 26 AWG is fine. Power wires to the lid
servo should be 20 AWG or heavier.

### 4.2 Servo rail cutoff (GPIO38)

A high-side P-channel MOSFET switch, driven by a small N-FET so the logic is
the right way up:

```
                     5 V rail in
                          │
                  ┌───────┴────────┐
             ┌────┤ S   P-FET (e.g. IRF4905, AO3401 for low current)
             │    │ G           D ├────► SERVO RAIL OUT
             │    └───────┬────────┘
          10k│            │
             │            │
   GPIO38 ──[1k]──┤ G  N-FET (2N7002 / 2N7000)
                  │ S ── GND
```

- GPIO38 **HIGH** → N-FET on → P-FET gate pulled low → servo rail **on**.
- GPIO38 **LOW / floating / ESP32 unpowered** → servo rail **off**.

That last line is the point: the safe state is the default state.

For currents above ~3 A, use a proper high-side load switch or an automotive
relay instead of a small SOT-23 P-FET.

### 4.3 I²C bus

| Device | SDA | SCL | VIN | GND | Addr |
|---|---|---|---|---|---|
| VL53L0X — throat | 8 | 9 | 3V3 | Star GND | 0x30 |
| VL53L0X — approach | 8 | 9 | 3V3 | Star GND | 0x31 |
| SSD1306 OLED | 8 | 9 | 3V3 | Star GND | 0x3C |

Plus `XSHUT`: throat → GPIO47, approach → GPIO48.

One pair of 4.7 kΩ pull-ups to **3V3** total for the whole bus. Adafruit
VL53L0X breakouts include 10 kΩ pull-ups; three modules in parallel gives
~3.3 kΩ, which is still fine at 400 kHz over short wires. Keep the I²C run
under 300 mm, and route it away from the servo power wires — twisting SDA/SCL
with a ground wire helps if you must run them alongside.

### 4.4 Switches and buttons

All are wired **switch → GPIO, other side → GND**, with the internal pull-up
enabled in firmware. No external resistors needed.

| Signal | GPIO | Type | Wiring note |
|---|---|---|---|
| Lid closed limit | 10 | SPDT microswitch | Use **COM → GND, NC → GPIO** so a severed wire reads "not closed". |
| Lid open limit | 11 | SPDT microswitch | Same convention. |
| NORMAL MODE | 12 | 19 mm latching pushbutton | Switch contact only; the lamp is a separate pair. |
| NORMAL MODE lamp | 2 | LED in the switch body | Through an N-FET, 5 V, with the switch's own series resistor (check your part — many 19 mm switches want 12 V; use a resistor or a 12 V feed for those). |
| Hidden trigger | 13 | Micro tactile switch | Mounted where the operator's hand rests. See the demo guide. |
| IR break-beam | 14 | 3-pin IR module OUT | Powered from 3V3. If your module is 5 V-only, level-shift the output. |

### 4.5 Audio — MAX98357A

| MAX98357A | ESP32-S3 |
|---|---|
| VIN | 5 V (audio rail) |
| GND | Star GND |
| DIN | GPIO21 |
| BCLK | GPIO17 |
| LRC | GPIO18 |
| GAIN | Leave floating for 9 dB, or tie to GND for 12 dB |
| SD | Leave floating (enabled, mono L+R) |

Speaker: 4 Ω 3 W, on the `+` / `−` screw terminals. Never ground either
speaker terminal — the output is a bridge-tied load.

### 4.6 LEDs

| WS2812B strip | To |
|---|---|
| 5 V | LED rail |
| GND | Star GND |
| DIN | GPIO16 through 330 Ω |

The ESP32-S3 outputs 3.3 V logic and WS2812B nominally wants 0.7 × VDD = 3.5 V.
It usually works. If the first pixel flickers or shows the wrong colour, add a
74AHCT125 level shifter, or power the strip from 4.5 V instead of 5 V.

---

## 5. Connection table — remote

| Signal | GPIO | Wiring |
|---|---|---|
| UP / DOWN / LEFT / RIGHT / OK / OPEN / CLOSE | 0, 1, 3, 7, 10, 20, 21 | 16 mm buttons, one side to GPIO, other to GND |
| Aux ladder | 4 | See `PINOUT.md` §2.3 |
| OLED SDA / SCL | 5 / 6 | 3V3 + GND from the board |
| Status LED | 8 | Onboard, no wiring |
| SECRET | 9 | Onboard BOOT button |

Power: a 2000 mAh Li-ion cell into the board's battery input, or simply a USB
power bank in the battery compartment. The remote draws ~45 mA average, so
either lasts a full event. There is no charging circuit in this design — if
you add a TP4056, keep it away from the antenna, which is decorative and
therefore attracts curiosity.

---

## 6. Loom and strain relief

- Use JST-XH or Dupont **with locking shells** for anything that crosses a
  module boundary. A vibrating servo will walk a bare Dupont pin off its
  header in about forty lid cycles.
- Label both ends of every harness. The tray slides out with the loom
  attached; you will still need to unplug it eventually.
- Route servo power and I²C on opposite sides of the tray.
- Cable-tie the lid servo's loom to the body **with a service loop** — the
  lid moves, the loom must not be in tension at either end of travel.
- Heat-shrink every solder joint. Splices inside a machine that shakes itself
  are a failure looking for an audience.

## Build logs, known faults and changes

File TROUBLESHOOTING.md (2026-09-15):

# TROUBLESHOOTING

The failures you are actually going to hit, roughly in the order you will hit
them.

**First, always:** open the serial monitor at 115200 and read the heartbeat.

```
[hb] IDLE/IDLE lid=0 ang=0 frus=0 thr=8190mm app=1240mm cyc=37 rx=412
```

A **frozen** heartbeat means a hung `loop()` — a software problem. A heartbeat
that keeps ticking while nothing moves means a hung mechanism — a hardware
problem. Knowing which one you have saves you an hour.

---

## 1. ESP32 resets, or `Brownout detector was triggered`

**By far the most common failure on this build.** It appears the moment the
lid first moves.

| Cause | Fix |
|---|---|
| Servos powered from the ESP32's 5 V pin | Give them their own rail from the PSU. `WIRING.md` §1, rule 1. This is almost always the answer. |
| No bulk capacitance | Fit the 1000 µF **at the servo distribution point**, not next to the PSU. |
| Bulk cap too far from the servos | Move it. Wire inductance defeats a distant capacitor. |
| Undersized supply | 5 V 5 A. A 2 A phone charger will not do this. |
| Thin power wiring | 18–20 AWG on the servo rail. Voltage drop under a 2.5 A stall is real. |
| Daisy-chained grounds | Star ground. `WIRING.md` §1, rule 2. |

Confirm with a multimeter on the servo rail while the lid moves. Below 4.6 V
is your problem.

---

## 2. Servo jitter, buzzing, or hunting

| Symptom | Cause | Fix |
|---|---|---|
| Buzzes constantly while parked | Servo still attached and hunting | The firmware detaches after `LID_IDLE_DETACH_MS`. If it does not, check `lid.update()` is being called every loop. |
| Buzzes only at an endpoint | Commanded past the mechanical stop | Back `LID_ANGLE_CLOSED`/`OPEN` off by 2–3°. **Do not leave it straining** — it will cook the servo. |
| Random twitching | Noise on the signal line | Route the signal away from servo power. Keep it short. Add 100 nF at the servo. |
| Twitches at boot | Normal — servos snap to position on attach | Cosmetic. Reduce by keeping the boot angles close to the rest positions. |
| Slow or weak | Rail sagging | See §1. |

---

## 3. A VL53L0X does not appear on the bus

| Cause | Fix |
|---|---|
| **XSHUT floating** | The usual answer. Both sensors boot at 0x29; they must be held in reset and brought up one at a time. Confirm GPIO47/48 actually reach the breakouts. |
| Wrong wiring on VIN | Adafruit breakouts take 3–5 V, some clones are 3V3-only. Check yours. |
| No pull-ups | 4.7 kΩ on SDA and SCL to 3V3. |
| Too many pull-ups | Three breakouts each with 10 kΩ gives ~3.3 kΩ, which is fine. Six is not. Cut the jumpers on the extras if the bus looks sluggish. |
| I²C run too long | Keep it under 300 mm. Twist SDA/SCL with a ground wire. |
| Address collision | The OLED is 0x3C; some are 0x3D. Change `OLED_ADDR` in `display.cpp`. |

Serial says `[sensors] THROAT ToF did not answer` — that message means
`begin()` failed, so it is a bus or XSHUT problem, not a threshold problem.

---

## 4. The sensor reads 8190 forever

8190 is the driver's out-of-range marker.

| Cause | Fix |
|---|---|
| **The bracket is shadowing the emitter** | The most common mechanical cause. `tof_bracket` holds the sensor 4 mm proud with a window wider than the PCB — do not close that window up to look neater. |
| Nothing actually in range | Expected. An empty throat genuinely reads out-of-range. |
| Target too dark or too shiny | Black matt foam and mirror-finish foil are the ToF worst cases. This is why the IR channel exists. |
| Sensor pointing into open space | The approach sensor should see a wall/floor at a known distance, not infinity. |
| Cover glass fingerprinted | Clean it. |

---

## 5. False detections / the lid opens at nothing

| Cause | Fix |
|---|---|
| Threshold too close to the resting reading | Widen the gap between `TOF_THROAT_OBJECT_MM` and the empty-throat value. |
| Not enough hysteresis | Raise `TOF_CONFIRM_SAMPLES` to 3. Keep `TOF_THROAT_CLEAR_MM` at least 50 mm above `OBJECT_MM`. |
| The lid itself entering the ToF cone | Geometry problem. Re-aim the throat sensor so it never sees the lid at any angle. Check at every point in travel, not just closed. |
| IR module triggering on ambient IR | Shade it, or turn its trim pot down. Stage lights and sunlight both emit IR. |
| Ground bounce from servo current | Star ground. §1. |

---

## 6. The lid will not move / `LID ERROR`

Display shows `LID ERROR / Have you tried turning me off?`

| Cause | Fix |
|---|---|
| A limit switch never asserted | The firmware refuses to trust the servo angle alone. Check the switch is made **just before** the mechanical stop, and that it is wired COM→GND / NC→GPIO. |
| Switch wired NO instead of NC | It will read "always closed" or "never closed". Rewire. |
| Mechanical binding | Disconnect the linkage and move the lid by hand. It must fall freely through the whole arc. Fix binding mechanically — no firmware setting compensates for a stiff hinge. |
| Servo underpowered for the lid | Redo the torque sum. `CAD_README.md` §1. |
| Servo rail off | GPIO38 low, master switch off, or a blown fuse. |
| `LID_LIMIT_TIMEOUT_MS` too short for a slow close | Only raise this once you have confirmed the mechanism is genuinely fine. |

To clear a fault without a power cycle: press the hidden trigger. The bin runs
`clearError()`, homes slowly, and displays `PRETENDING THAT'S FIXED`.

---

## 7. The remote does nothing

| Cause | Fix |
|---|---|
| **Different channels** | Both ends must call `esp_wifi_set_channel()`. The single most common ESP-NOW failure — the link silently does nothing. |
| **`protocol.h` copies have diverged** | They must be byte-identical. A mismatch fails the checksum on every packet. `diff` them. |
| USB CDC On Boot disabled on the remote | GPIO20/21 are buttons. Without USB CDC they are UART0 and the remote appears dead. |
| Different `DUSTE_DEVICE_ID` | Both must be `0x2A`. |
| Buttons held during boot on GPIO 2/8/9 | Strapping pins. Release and reset. |
| It **is** working | Check the serial log. `[remote] asked OPEN -> doing CLOSE` means the link is perfect and the bin is simply refusing you. That is the product. |

`packetsRejected()` climbing while `packetsReceived()` stays flat means
packets are arriving and failing validation — checksum, version or device ID.

---

## 8. Audio problems

| Symptom | Cause | Fix |
|---|---|---|
| Silence | LittleFS not uploaded | Tools → ESP32 Sketch Data Upload. Serial will say `missing clip /boot.wav`. |
| Silence, and `ESP_I2S.h not found` at compile | Arduino core 2.x | Upgrade to core 3.x, or set `AUDIO_BACKEND` to `AUDIO_DFPLAYER`. |
| Silence, `I2S init failed` | Pin conflict | Check GPIO17/18/21 are not double-assigned. |
| Loud hiss between clips | Amp enabled with no data | Normal for MAX98357A. Tie SD through a resistor divider, or ignore it. |
| Distorted | Clipping | Lower `AUDIO_VOLUME_DEFAULT`, or record the source clips quieter. |
| Crackling during servo movement | Shared power rail | Separate the audio rail, add the 220 µF. |
| Plays too fast/slow | Sample rate mismatch | The parser reads the rate from the file, but only 16-bit PCM is supported. Re-export as 16-bit mono. |
| Choppy | Loop starved | Something is blocking. Look for a `delay()` you added. |

---

## 9. LED problems

| Symptom | Fix |
|---|---|
| First pixel wrong colour or flickering | 3.3 V data into a 5 V strip. Add a 74AHCT125, or run the strip from 4.5 V. |
| All pixels wrong colour | Wrong colour order. Change `NEO_GRB` to `NEO_RGB` in `leds.cpp`. |
| Flickering under load | Missing 470 µF at the strip, or missing 330 Ω on the data line. |
| Dim or brownouts at full white | 12 pixels at full white is ~720 mA. Lower `LED_BRIGHTNESS`. |
| Nothing at all | Data direction — WS2812 strips are directional. Follow the arrows. |

---

## 10. Mechanical binding

| Symptom | Fix |
|---|---|
| Lid stiff at one point in the arc | Hinge brackets not coaxial. Loosen, align, retighten. |
| Lid stiff throughout | Pin bore too tight. Raise `fit_loose` and reprint, or ream the bore. |
| Linkage binding at the extremes | `link_len` wrong. That is what the slotted holes in `servo_mount` are for. |
| Finger fouls the hatch | Cartridge not square, or `DOOR_ANGLE_OPEN` too small. |
| Finger misses the switch sideways | Fix the cartridge mount, not the firmware. `BUILD_GUIDE.md` §5.1. |
| Hatch does not close fully | Door servo horn fitted at the wrong angle. Re-fit at `DOOR_ANGLE_SHUT`. |
| Grinding noise | Something is being driven into a hard stop. **Power off immediately** and find it before you strip a gearbox. |

---

## 11. Nothing works and the demo is in ten minutes

In order:

1. **Power cycle.** Watch the self-test — it tells you which subsystem failed.
2. **Check the fuse.**
3. **Reseat every connector.** Vibration walks Dupont pins off headers.
4. Anything on the self-test says `FAIL`, disable it and demo without it:
   `USE_TOF_APPROACH 0`, `USE_IR_THROAT 0`, `USE_EYE_TILT 0`,
   `AUDIO_BACKEND AUDIO_NONE`. The machine is designed to degrade.
5. **Lid dead?** Demo the remote and the finger. Still funny.
6. **Finger dead?** Swap the spare cartridge — four screws and one connector.
7. **Sensors dead?** The hidden trigger fires a complete success reaction on
   demand. Nobody in the audience can tell.
8. **Remote dead?** The bin's own behaviour and the NORMAL MODE punchline
   carry the demo on their own.

The whole architecture is built so that no single failure takes the demo down.
Use that. Do not stand there trying to fix the root cause while the judges
wait — degrade, present, fix afterwards.

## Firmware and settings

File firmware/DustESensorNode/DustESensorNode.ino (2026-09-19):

// =============================================================================
//  DUST-E SENSOR NODE - Arduino UNO Q, MCU side (STM32U585, Zephyr Arduino core)
//
//  This is the UNO Q's contribution to physical safety. It owns every sensor
//  that can stop the robot, and it never touches a motor - the XIAO ESP32-S3
//  ("DustEBody") is the only thing that drives the wheels. The two boards
//  agree on exactly one signal:
//
//      MOTION_OK (this board's D9 -> XIAO D7)
//
//  toggled here every loop pass while nothing this board can see is a hazard,
//  read there as a pulse train (edges required, not a level - see
//  firmware/DustEBody/src/safety/reflex.cpp and
//  brain/dustebrain/body/simbody.py). A crashed MCU, a hung loop, a cut wire
//  and an actual obstacle all stop the pulses, and the XIAO treats them all
//  the same way: forward motion blocked.
//
//  Board: Arduino UNO Q (arduino:zephyr:unoq). Same board, same core, same
//  OLED driver approach as firmware/UselessBox/UselessBox_UnoQ/ - this is a
//  different program for the same physical wiring, repurposed for DUST-E:
//
//      D2  / D4   HC-SR04 #1 TRIG / ECHO   (unchanged)
//      A0  / A1   HC-SR04 #2 TRIG / ECHO   (unchanged)
//      A2  / A3   HC-SR04 #3 TRIG / ECHO   (unchanged)
//      D3         active buzzer            (unchanged)
//      D12        NORMAL MODE switch       (unchanged)
//      D13        IR obstacle sensor       (unchanged)
//      SDA/SCL    SSD1306 OLED (Wire2), + INA219 battery monitor @0x40
//      D5         BUMPER_L   (NC to GND, pull-up: a broken wire reads "hit")
//      D6         BUMPER_R   (same)
//      D7         CLIFF_L    (digital IR reflectance, fail-safe polarity)
//      D8         CLIFF_R    (same)
//      D9         MOTION_OK  -> XIAO D7
//      D10        ESTOP_SENSE (aux NC contact of the mushroom switch)
//      D11        spare (the lid servo moved to the XIAO)
//
//  See docs/COMPANION_ARCHITECTURE.md section 6.2 for the full reasoning.
//
//  HONESTY RULE: cliff sensors and bumpers are not fitted on the bench yet
//  (docs/COMPANION_BOM.md rows 8-9). HW_CLIFF and HW_BUMPERS below are false
//  until they are. An uninstalled input is never read as a hazard AND never
//  read as "safe" - it is simply left out of the hazard vote, and its true
//  state is reported honestly in the periodic status line so nobody mistakes
//  "not wired" for "checked and clear". The brain is the thing that decides
//  whether autonomy may run without them (it must not - see the BOM).
// =============================================================================
#include <Wire.h>
#include <Adafruit_GFX.h>

// ---------------------------------------------------------------------------
// Hardware inventory - flip to true at the same time the part is soldered in.
// ---------------------------------------------------------------------------
#define HW_CLIFF     0   // TCRT5000 x2 - docs/COMPANION_BOM.md row 8
#define HW_BUMPERS   0   // micro limit switch x2 - row 9
#define HW_ESTOP     0   // aux NC contact wired to D10 - fit with the E-stop, row 1
#define HW_BATTERY   0   // INA219 on Wire2 @0x40 - row 4
#define HW_IR_THROAT 1   // the IR sensor already on D13 from the UselessBox wiring

// ---------------------------------------------------------------------------
// Pins
// ---------------------------------------------------------------------------
#define SENSOR_COUNT 3
const int TRIG_PINS[SENSOR_COUNT] = { 2, A0, A2 };
const int ECHO_PINS[SENSOR_COUNT] = { 4, A1, A3 };
#define ECHO_TIMEOUT_US 12000UL     // ~2 m; keeps a no-echo read from stalling the loop
#define STOP_DISTANCE_CM 20.0f      // any sensor closer than this is a hazard

#define BUZZER_PIN 3
#define IR_THROAT_PIN 13
#define IR_THROAT_NO_OBJECT HIGH    // flip if your module's output logic is opposite

#define SWITCH_NORMAL_PIN 12        // NORMAL MODE gag switch, active LOW

#define PIN_BUMPER_L   5
#define PIN_BUMPER_R   6
#define PIN_CLIFF_L    7
#define PIN_CLIFF_R    8
#define PIN_MOTION_OK  9
#define PIN_ESTOP_SENSE 10

// Bumpers and E-stop sense are wired NC-to-GND through a pull-up: closed
// circuit (LOW) is the safe, at-rest state. A press OR a broken wire both
// open the circuit and read HIGH - "unknown" and "hit" are deliberately the
// same failure here.
#define CONTACT_SAFE LOW
#define CONTACT_HAZARD HIGH

// Cliff sensor polarity depends on the module; TCRT5000-style reflectance
// boards read LOW when the beam bounces back off a floor (safe) and HIGH
// when there is nothing to reflect off (a drop-off). Flip if yours differs.
#define CLIFF_SAFE LOW
#define CLIFF_HAZARD HIGH

#define INA219_ADDR 0x40

// ---------------------------------------------------------------------------
// OLED - same minimal driver as UselessBox_UnoQ: Adafruit_SSD1306 does not
// compile against the Zephyr core, and U8g2's hardware-I2C path is hard-wired
// to Wire, but on the UNO Q the header SDA/SCL pins are i2c3 (Wire2). Adafruit
// GFX only needs drawPixel(), so subclass it and drive the bus directly.
// ---------------------------------------------------------------------------
#define OLED_BLACK 0
#define OLED_WHITE 1
#define FRAME_MS 50

class OledFace : public Adafruit_GFX {
  public:
    OledFace() : Adafruit_GFX(128, 64) {}

    bool begin() {
        TwoWire *buses[] = { &Wire2, &Wire1, &Wire };
        const uint8_t addrs[] = { 0x3C, 0x3D };
        for (uint8_t b = 0; b < 3; b++) {
            buses[b]->begin();
            for (uint8_t a = 0; a < 2; a++) {
                buses[b]->beginTransmission(addrs[a]);
                if (buses[b]->endTransmission() == 0) {
                    wire = buses[b];
                    addr = addrs[a];
                    initPanel();
                    return true;
                }
            }
        }
        return false;
    }

    void drawPixel(int16_t x, int16_t y, uint16_t color) override {
        if (x < 0 || x >= 128 || y < 0 || y >= 64) return;
        uint16_t i = x + (y / 8) * 128;
        uint8_t bit = 1 << (y & 7);
        if (color) buf[i] |= bit; else buf[i] &= ~bit;
    }

    void clear() { memset(buf, 0, sizeof(buf)); }

    void flush() {
        cmd(0x21); cmd(0); cmd(127);
        cmd(0x22); cmd(0); cmd(7);
        for (uint16_t i = 0; i < sizeof(buf); i += 128) {
            wire->beginTransmission(addr);
            wire->write((uint8_t)0x40);
            wire->write(buf + i, 128);
            wire->endTransmission();
        }
    }

  private:
    void cmd(uint8_t c) {
        wire->beginTransmission(addr);
        wire->write((uint8_t)0x00);
        wire->write(c);
        wire->endTransmission();
    }

    void initPanel() {
        static const uint8_t seq[] = {
            0xAE, 0xD5, 0x80, 0xA8, 0x3F, 0xD3, 0x00, 0x40,
            0x8D, 0x14, 0x20, 0x00, 0xA1, 0xC8, 0xDA, 0x12,
            0x81, 0xCF, 0xD9, 0xF1, 0xDB, 0x40, 0xA4, 0xA6, 0x2E, 0xAF
        };
        for (uint8_t i = 0; i < sizeof(seq); i++) cmd(seq[i]);
    }

    TwoWire *wire = nullptr;
    uint8_t addr = 0x3C;
    uint8_t buf[1024];
};

OledFace face;
bool hasDisplay = false;
unsigned long nextFrame = 0;

// ---------------------------------------------------------------------------
// State
// ---------------------------------------------------------------------------
int sensorIndex = 0;
float lastDistanceCm[SENSOR_COUNT] = { -1, -1, -1 };

bool motionOkLevel = LOW;
unsigned long lastStatusPrint = 0;
#define STATUS_PRINT_MS 1000

bool buzzing = false;
unsigned long buzzStopAt = 0;
#define BUZZER_DURATION_MS 10000UL

// ---------------------------------------------------------------------------
void setup() {
    Serial.begin(115200);
    delay(300);
    Serial.println();
    Serial.println(F("=== DUST-E SENSOR NODE (UNO Q) ==="));

    for (int i = 0; i < SENSOR_COUNT; i++) {
        pinMode(TRIG_PINS[i], OUTPUT);
        digitalWrite(TRIG_PINS[i], LOW);
        pinMode(ECHO_PINS[i], INPUT);
    }

    pinMode(BUZZER_PIN, OUTPUT);
    digitalWrite(BUZZER_PIN, LOW);

    pinMode(IR_THROAT_PIN, INPUT);
    pinMode(SWITCH_NORMAL_PIN, INPUT_PULLUP);

    pinMode(PIN_BUMPER_L, INPUT_PULLUP);
    pinMode(PIN_BUMPER_R, INPUT_PULLUP);
    pinMode(PIN_CLIFF_L, INPUT);
    pinMode(PIN_CLIFF_R, INPUT);
    pinMode(PIN_ESTOP_SENSE, INPUT_PULLUP);

    pinMode(PIN_MOTION_OK, OUTPUT);
    digitalWrite(PIN_MOTION_OK, LOW);   // starts low: no pulses until the loop runs

    hasDisplay = face.begin();
    if (hasDisplay) { face.clear(); face.flush(); }

    if (HW_BATTERY) {
        Wire2.beginTransmission(INA219_ADDR);
        if (Wire2.endTransmission() != 0) {
            Serial.println(F("WARN: HW_BATTERY set but INA219 did not answer at 0x40"));
        }
    }

    // Serial (BridgeMonitor<>, Zephyr core) has print()/println() but no printf().
    Serial.print(F("display:")); Serial.print(hasDisplay);
    Serial.print(F(" cliff:"));  Serial.print(HW_CLIFF);
    Serial.print(F(" bumpers:")); Serial.print(HW_BUMPERS);
    Serial.print(F(" estop:")); Serial.print(HW_ESTOP);
    Serial.print(F(" battery:")); Serial.println(HW_BATTERY);
    Serial.println(F("MOTION_OK will start toggling once the loop is running."));
}

// ---------------------------------------------------------------------------
// One HC-SR04, blocking on pulseIn() for up to ECHO_TIMEOUT_US. That is fine
// here specifically because this board drives no motor: the worst case is a
// slightly stale reading on the OTHER two sensors this pass, never a stalled
// motor update. (On the XIAO this same call would be a straight-up bug - see
// docs/COMPANION_ARCHITECTURE.md section 6.2, "why sensors on the MCU are
// acceptable here".)
// ---------------------------------------------------------------------------
float readDistanceCm(int trigPin, int echoPin) {
    digitalWrite(trigPin, LOW);
    delayMicroseconds(2);
    digitalWrite(trigPin, HIGH);
    delayMicroseconds(10);
    digitalWrite(trigPin, LOW);

    unsigned long duration = pulseIn(echoPin, HIGH, ECHO_TIMEOUT_US);
    if (duration == 0) return -1.0f;          // no echo: out of range, not a reading of 0
    return duration * 0.0343f / 2.0f;
}

void pollOneUltrasonic() {
    lastDistanceCm[sensorIndex] = readDistanceCm(TRIG_PINS[sensorIndex], ECHO_PINS[sensorIndex]);
    sensorIndex = (sensorIndex + 1) % SENSOR_COUNT;
}

bool ultrasonicHazard() {
    for (int i = 0; i < SENSOR_COUNT; i++) {
        if (lastDistanceCm[i] > 0 && lastDistanceCm[i] < STOP_DISTANCE_CM) return true;
    }
    return false;
}

bool bumperHazard() {
    if (!HW_BUMPERS) return false;
    return digitalRead(PIN_BUMPER_L) == CONTACT_HAZARD
        || digitalRead(PIN_BUMPER_R) == CONTACT_HAZARD;
}

bool cliffHazard() {
    if (!HW_CLIFF) return false;
    return digitalRead(PIN_CLIFF_L) == CLIFF_HAZARD
        || digitalRead(PIN_CLIFF_R) == CLIFF_HAZARD;
}

bool estopHazard() {
    if (!HW_ESTOP) return false;
    return digitalRead(PIN_ESTOP_SENSE) == CONTACT_HAZARD;
}

// ---------------------------------------------------------------------------
void handleIrThroatBuzzer() {
    if (buzzing) {
        if (millis() >= buzzStopAt) { digitalWrite(BUZZER_PIN, LOW); buzzing = false; }
        return;
    }
    if (HW_IR_THROAT && digitalRead(IR_THROAT_PIN) == IR_THROAT_NO_OBJECT) {
        digitalWrite(BUZZER_PIN, HIGH);
        buzzing = true;
        buzzStopAt = millis() + BUZZER_DURATION_MS;
    }
}

void drawFace(bool hazard) {
    if (!hasDisplay) return;
    if (millis() < nextFrame) return;
    nextFrame = millis() + FRAME_MS;

    face.clear();
    // Deliberately minimal: this board's face is a status indicator, not the
    // expressive one - FACE_SET commands from the brain go through the XIAO's
    // lid/leds path today and the OLED here purely reports sensor node health.
    face.fillRoundRect(30, 18, 20, hazard ? 8 : 20, 6, OLED_WHITE);   // "eye" narrows on hazard
    face.fillRoundRect(78, 18, 20, hazard ? 8 : 20, 6, OLED_WHITE);
    if (hazard) {
        face.drawLine(40, 50, 88, 50, OLED_WHITE);   // flat "concerned" mouth
    } else {
        face.drawLine(40, 48, 64, 54, OLED_WHITE);
        face.drawLine(64, 54, 88, 48, OLED_WHITE);
    }
    face.flush();
}

void printStatus(bool hazard, const char *why) {
    if (millis() - lastStatusPrint < STATUS_PRINT_MS) return;
    lastStatusPrint = millis();
    // Serial (BridgeMonitor<>, Zephyr core) has print()/println() but no printf().
    Serial.print(F("[sensor] hazard=")); Serial.print(hazard);
    Serial.print(F(" (")); Serial.print(why); Serial.print(F(")"));
    Serial.print(F(" us=")); Serial.print(lastDistanceCm[0], 0);
    Serial.print(F("/")); Serial.print(lastDistanceCm[1], 0);
    Serial.print(F("/")); Serial.print(lastDistanceCm[2], 0);
    Serial.print(F(" cliff=")); Serial.print(HW_CLIFF ? digitalRead(PIN_CLIFF_L) : -1);
    Serial.print(F(",")); Serial.print(HW_CLIFF ? digitalRead(PIN_CLIFF_R) : -1);
    Serial.print(F(" bump=")); Serial.print(HW_BUMPERS ? digitalRead(PIN_BUMPER_L) : -1);
    Serial.print(F(",")); Serial.print(HW_BUMPERS ? digitalRead(PIN_BUMPER_R) : -1);
    Serial.print(F(" estop=")); Serial.print(HW_ESTOP ? digitalRead(PIN_ESTOP_SENSE) : -1);
    Serial.print(F(" normal_sw=")); Serial.print(digitalRead(SWITCH_NORMAL_PIN) == LOW);
    Serial.print(F(" motion_ok=")); Serial.println(motionOkLevel);
}

// ---------------------------------------------------------------------------
void loop() {
    pollOneUltrasonic();
    handleIrThroatBuzzer();

    const char *why = "clear";
    bool hazard = false;
    if (ultrasonicHazard())      { hazard = true; why = "obstacle"; }
    else if (cliffHazard())      { hazard = true; why = "cliff"; }
    else if (bumperHazard())     { hazard = true; why = "bumper"; }
    else if (estopHazard())      { hazard = true; why = "estop_sense"; }

    // Toggle every pass rather than on a timer: this IS the liveness signal,
    // so its own cadence should track the loop's health directly. Worst-case
    // loop period here is one pulseIn() timeout (12 ms), giving the XIAO's
    // 150 ms / 2-edge window enormous margin.
    if (!hazard) {
        motionOkLevel = !motionOkLevel;
        digitalWrite(PIN_MOTION_OK, motionOkLevel);
    } else {
        // Hold the line low while a hazard is active. A held level produces
        // no edges, which is exactly the "no pulses" state the XIAO already
        // treats as a veto - the same code path as a dead sensor node.
        motionOkLevel = LOW;
        digitalWrite(PIN_MOTION_OK, LOW);
    }

    drawFace(hazard);
    printStatus(hazard, why);
}

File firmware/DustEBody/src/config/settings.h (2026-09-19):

// =============================================================================
//  settings.h - every tunable number in the DUST-E body.
//
//  These values are the same numbers as the `body:` block in
//  brain/config/default.yaml. That is not a coincidence and not decoration:
//  brain/dustebrain/body/simbody.py is a reference implementation of the rules
//  below, and brain/tests/test_simbody.py is the failsafe matrix as tests. If
//  a number here and a number there disagree, the tests are testing a robot
//  that does not exist.
//
//  Anything that can stop a motor lives in this file. Nothing in the protocol
//  can raise a ceiling defined here - the `limits` message may only lower one.
// =============================================================================
#pragma once
#include <stdint.h>

#define DUSTE_BODY_VERSION "0.1.0"
#define SERIAL_BAUD 115200

// ---------------------------------------------------------------------------
// LINK (USB CDC to the UNO Q)
// ---------------------------------------------------------------------------
static const uint16_t LINK_TIMEOUT_MS      = 300;   // no heartbeat -> hard stop
static const uint16_t CMD_TTL_DEFAULT_MS   = 300;   // a velocity command expires
static const uint16_t CMD_TTL_MAX_MS       = 500;   // ...and is clamped to this
static const uint16_t TELEMETRY_MS         = 50;    // 20 Hz
static const uint16_t LINK_LINE_MAX             = 512;   // longer inbound lines are dropped

// ---------------------------------------------------------------------------
// MOTORS
//
//   Percent in, percent out: the brain never sends raw duty. MIN_PCT exists
//   because a loaded DC motor below roughly a quarter duty buzzes and heats
//   instead of turning, so any non-zero request is lifted to it.
//
//   DECEL_MULT is the one asymmetry that matters: stopping is always allowed
//   to outrun starting. Never set it below 1.
// ---------------------------------------------------------------------------
static const uint32_t MOTOR_PWM_FREQ_HZ    = 5000;
static const uint8_t  MOTOR_PWM_BITS       = 8;
static const uint8_t  MOTOR_AUTO_MAX_PCT   = 45;    // ceiling while driving itself
static const uint8_t  MOTOR_MANUAL_MAX_PCT = 70;    // ceiling for a human at the dashboard
static const uint8_t  MOTOR_MIN_PCT        = 22;
static const uint8_t  MOTOR_ACCEL_PCT      = 6;     // per tick
static const uint8_t  MOTOR_DECEL_MULT     = 3;
static const uint16_t MOTOR_TICK_MS        = 20;

// ---------------------------------------------------------------------------
// MOTION_OK - the sensor veto from the UNO Q MCU.
//
//   One wire, toggled by the MCU's main loop while its sensors see no hazard.
//   Edges are required, not a level: a stuck-high wire, a stuck-low wire, a
//   cut wire, a crashed MCU and a hung loop then all look identical, and are
//   all handled identically.
//
//   While the pulses are absent, only a short slow reverse is allowed. Every
//   sensor faces forward or down-forward, so backing away is the one safe
//   escape - and the cooldown stops it becoming a habit.
// ---------------------------------------------------------------------------
static const uint16_t MOTION_OK_WINDOW_MS   = 150;
static const uint8_t  MOTION_OK_MIN_EDGES   = 2;
static const uint8_t  ESCAPE_DUTY_PCT       = 25;
static const uint16_t ESCAPE_MS             = 800;
static const uint16_t ESCAPE_COOLDOWN_MS    = 2000;


// ---------------------------------------------------------------------------
// BATTERY
//
//   Measured by the INA219 on the UNO Q sensor node and forwarded over the
//   link; the body enforces the limit because the body owns the motors.
//   Until a pack is fitted the value stays unknown and is never invented.
//   These defaults are sized for a 3S Li-ion pack - set yours.
// ---------------------------------------------------------------------------
static const uint16_t BATTERY_LOW_MV      = 10500;  // brain: head home
static const uint16_t BATTERY_CRITICAL_MV = 9800;   // body: refuse to move
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

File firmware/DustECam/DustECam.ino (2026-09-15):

// =============================================================================
//  DUST-E CAM
//
//  An ESP32-CAM (AI-Thinker module, OV2640) that gives the web remote a
//  camera that is not the phone's own. It runs no detector - an ESP32 cannot
//  run a useful object detector, and pretending otherwise would be the one
//  kind of lie this project does not tell. Instead it does the two things it
//  can do well:
//
//    GET /capture   one JPEG, fresh, with Access-Control-Allow-Origin: *
//    GET /stream    MJPEG, for a human to look at
//    GET /status    JSON: frame size, uptime, free heap
//
//  The phone's VISION tab points at this board, polls /capture a few times a
//  second, runs COCO-SSD in the browser, and reports the result to the bin.
//  The CORS header is what makes that possible: without it the browser may
//  display the picture but is not allowed to read its pixels.
//
//  Network: joins the bin's own access point by default (DUST-E-SETUP), so
//  the whole thing works in a room with no Wi-Fi. Change WIFI_SSID/PASS below
//  to put it on a house network alongside the bin instead. mDNS: trashcam.local
//
//  Wiring: nothing beyond 5 V and GND. The board's UART0 (U0T/U0R) is free
//  for programming. If you ever add an on-board detector, reportToBin() at
//  the bottom already knows how to tell the bin what it saw.
// =============================================================================
#include <WiFi.h>
#include <ESPmDNS.h>
#include <HTTPClient.h>
#include <esp_camera.h>
#include <esp_http_server.h>
#include <esp_timer.h>

// ---------------------------------------------------------------------------
// Configuration
// ---------------------------------------------------------------------------
#define WIFI_SSID      "DUST-E-SETUP"      // the bin's AP (see DustEWeb settings.h)
#define WIFI_PASS      "dustebin"
#define HOSTNAME       "trashcam"
#define BIN_HOST       "192.168.4.1"         // where /api/vision lives, if a detector is ever added

static const framesize_t FRAME_SIZE   = FRAMESIZE_VGA;   // 640x480; the browser downscales anyway
static const int         JPEG_QUALITY = 12;              // 10..63, lower is better and bigger
static const uint32_t    WIFI_TIMEOUT_MS = 15000;

// AI-Thinker ESP32-CAM pin map. Other modules differ - check yours.
#define PWDN_GPIO_NUM     32
#define RESET_GPIO_NUM    -1
#define XCLK_GPIO_NUM      0
#define SIOD_GPIO_NUM     26
#define SIOC_GPIO_NUM     27
#define Y9_GPIO_NUM       35
#define Y8_GPIO_NUM       34
#define Y7_GPIO_NUM       39
#define Y6_GPIO_NUM       36
#define Y5_GPIO_NUM       21
#define Y4_GPIO_NUM       19
#define Y3_GPIO_NUM       18
#define Y2_GPIO_NUM        5
#define VSYNC_GPIO_NUM    25
#define HREF_GPIO_NUM     23
#define PCLK_GPIO_NUM     22
#define FLASH_LED_GPIO     4

static httpd_handle_t httpd = nullptr;
static bool cameraOk = false;

// ---------------------------------------------------------------------------
static bool startCamera() {
    camera_config_t c = {};
    c.ledc_channel = LEDC_CHANNEL_0;
    c.ledc_timer   = LEDC_TIMER_0;
    c.pin_d0 = Y2_GPIO_NUM;  c.pin_d1 = Y3_GPIO_NUM;  c.pin_d2 = Y4_GPIO_NUM;  c.pin_d3 = Y5_GPIO_NUM;
    c.pin_d4 = Y6_GPIO_NUM;  c.pin_d5 = Y7_GPIO_NUM;  c.pin_d6 = Y8_GPIO_NUM;  c.pin_d7 = Y9_GPIO_NUM;
    c.pin_xclk = XCLK_GPIO_NUM;   c.pin_pclk = PCLK_GPIO_NUM;
    c.pin_vsync = VSYNC_GPIO_NUM; c.pin_href = HREF_GPIO_NUM;
    c.pin_sccb_sda = SIOD_GPIO_NUM; c.pin_sccb_scl = SIOC_GPIO_NUM;
    c.pin_pwdn = PWDN_GPIO_NUM;   c.pin_reset = RESET_GPIO_NUM;
    c.xclk_freq_hz = 20000000;
    c.pixel_format = PIXFORMAT_JPEG;
    c.frame_size   = FRAME_SIZE;
    c.jpeg_quality = JPEG_QUALITY;
    c.fb_count     = psramFound() ? 2 : 1;
    c.fb_location  = psramFound() ? CAMERA_FB_IN_PSRAM : CAMERA_FB_IN_DRAM;
    c.grab_mode    = CAMERA_GRAB_LATEST;      // /capture must be *now*, not a stale buffer

    if (esp_camera_init(&c) != ESP_OK) return false;

    sensor_t* s = esp_camera_sensor_get();
    if (s) {
        s->set_vflip(s, 0);
        s->set_hmirror(s, 0);
    }
    return true;
}

// ---------------------------------------------------------------------------
// HTTP. esp_http_server, like the CameraWebServer example, because it copes
// with a long-lived MJPEG connection without help.
// ---------------------------------------------------------------------------
static void cors(httpd_req_t* req) {
    httpd_resp_set_hdr(req, "Access-Control-Allow-Origin", "*");
    httpd_resp_set_hdr(req, "Cache-Control", "no-store");
}

static esp_err_t captureHandler(httpd_req_t* req) {
    if (!cameraOk) {
        httpd_resp_send_err(req, HTTPD_500_INTERNAL_SERVER_ERROR, "camera not initialised");
        return ESP_FAIL;
    }
    camera_fb_t* fb = esp_camera_fb_get();
    if (!fb) {
        httpd_resp_send_err(req, HTTPD_500_INTERNAL_SERVER_ERROR, "capture failed");
        return ESP_FAIL;
    }
    cors(req);
    httpd_resp_set_type(req, "image/jpeg");
    httpd_resp_set_hdr(req, "Content-Disposition", "inline; filename=capture.jpg");
    esp_err_t r = httpd_resp_send(req, (const char*)fb->buf, fb->len);
    esp_camera_fb_return(fb);
    return r;
}

static const char* STREAM_CT   = "multipart/x-mixed-replace;boundary=frame";
static const char* STREAM_BND  = "\r\n--frame\r\n";
static const char* STREAM_PART = "Content-Type: image/jpeg\r\nContent-Length: %u\r\n\r\n";

static esp_err_t streamHandler(httpd_req_t* req) {
    if (!cameraOk) {
        httpd_resp_send_err(req, HTTPD_500_INTERNAL_SERVER_ERROR, "camera not initialised");
        return ESP_FAIL;
    }
    cors(req);
    esp_err_t r = httpd_resp_set_type(req, STREAM_CT);
    if (r != ESP_OK) return r;
    char part[64];
    while (true) {
        camera_fb_t* fb = esp_camera_fb_get();
        if (!fb) return ESP_FAIL;
        size_t n = snprintf(part, sizeof(part), STREAM_PART, (unsigned)fb->len);
        r = httpd_resp_send_chunk(req, STREAM_BND, strlen(STREAM_BND));
        if (r == ESP_OK) r = httpd_resp_send_chunk(req, part, n);
        if (r == ESP_OK) r = httpd_resp_send_chunk(req, (const char*)fb->buf, fb->len);
        esp_camera_fb_return(fb);
        if (r != ESP_OK) return r;              // the viewer went away
    }
}

static esp_err_t statusHandler(httpd_req_t* req) {
    char buf[200];
    snprintf(buf, sizeof(buf),
             "{\"camera\":%s,\"frame\":\"%s\",\"uptime\":%lu,\"heap\":%u,\"psram\":%u,\"rssi\":%d}",
             cameraOk ? "true" : "false",
             FRAME_SIZE == FRAMESIZE_VGA ? "640x480" : "other",
             (unsigned long)(esp_timer_get_time() / 1000), (unsigned)ESP.getFreeHeap(),
             (unsigned)ESP.getFreePsram(), WiFi.RSSI());
    cors(req);
    httpd_resp_set_type(req, "application/json");
    return httpd_resp_send(req, buf, strlen(buf));
}
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

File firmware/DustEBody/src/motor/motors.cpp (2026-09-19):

#include "motors.h"
#include <Arduino.h>
#include "../config/pins.h"
#include "../config/settings.h"

Motors motors;

// Arduino-ESP32 3.x binds PWM to the pin itself; 2.x needs explicit channels.
// The XIAO ships with 3.x, but supporting both is one #if and saves the single
// most common "it will not compile" report.
#if defined(ESP_ARDUINO_VERSION_MAJOR) && ESP_ARDUINO_VERSION_MAJOR >= 3
  #define PWM_ATTACH(pin, ch)   ledcAttach((pin), MOTOR_PWM_FREQ_HZ, MOTOR_PWM_BITS)
  #define PWM_WRITE(pin, ch, d) ledcWrite((pin), (d))
#else
  #define PWM_ATTACH(pin, ch)   do { ledcSetup((ch), MOTOR_PWM_FREQ_HZ, MOTOR_PWM_BITS); \
                                     ledcAttachPin((pin), (ch)); } while (0)
  #define PWM_WRITE(pin, ch, d) ledcWrite((ch), (d))
#endif

static const uint8_t CH_L_IN1 = 0;
static const uint8_t CH_L_IN2 = 1;
static const uint8_t CH_R_IN3 = 2;
static const uint8_t CH_R_IN4 = 3;

void Motors::begin() {
    // Drive every input low before the PWM peripheral is attached, so the
    // window between reset and setup() is as short as the hardware allows.
    pinMode(PIN_MOTOR_L_IN1, OUTPUT); digitalWrite(PIN_MOTOR_L_IN1, LOW);
    pinMode(PIN_MOTOR_L_IN2, OUTPUT); digitalWrite(PIN_MOTOR_L_IN2, LOW);
    pinMode(PIN_MOTOR_R_IN3, OUTPUT); digitalWrite(PIN_MOTOR_R_IN3, LOW);
    pinMode(PIN_MOTOR_R_IN4, OUTPUT); digitalWrite(PIN_MOTOR_R_IN4, LOW);

    PWM_ATTACH(PIN_MOTOR_L_IN1, CH_L_IN1);
    PWM_ATTACH(PIN_MOTOR_L_IN2, CH_L_IN2);
    PWM_ATTACH(PIN_MOTOR_R_IN3, CH_R_IN3);
    PWM_ATTACH(PIN_MOTOR_R_IN4, CH_R_IN4);

    ceiling_ = MOTOR_AUTO_MAX_PCT;
    hardStop();
}

void Motors::setCeiling(uint8_t pct) {
    if (pct == 0) return;
    if (pct > MOTOR_MANUAL_MAX_PCT) pct = MOTOR_MANUAL_MAX_PCT;  // the compile-time wall
    ceiling_ = pct;
}

int16_t Motors::clampPct(int32_t pct) const {
    const int32_t lim = (int32_t)ceiling_;
    if (pct >  lim) pct =  lim;
    if (pct < -lim) pct = -lim;
    return (int16_t)pct;
}

void Motors::setTarget(int16_t leftPct, int16_t rightPct) {
    tgtL_ = clampPct(leftPct);
    tgtR_ = clampPct(rightPct);
}

void Motors::hardStop() {
    tgtL_ = tgtR_ = 0;
    curL_ = curR_ = 0;
    writeSide(true, 0);
    writeSide(false, 0);
}

int16_t Motors::ramp(int16_t cur, int16_t tgt) const {
    int16_t accel = MOTOR_ACCEL_PCT;
    int16_t step  = (abs(tgt) > abs(cur)) ? accel : (int16_t)(accel * MOTOR_DECEL_MULT);
    int16_t diff  = (int16_t)(tgt - cur);
    if (diff >= -step && diff <= step) return tgt;
    return (int16_t)(cur + (diff > 0 ? step : -step));
}

void Motors::tick(uint32_t now) {
    if ((uint32_t)(now - lastTick_) < MOTOR_TICK_MS) return;
    lastTick_ = now;
    curL_ = ramp(curL_, clampPct(tgtL_));
    curR_ = ramp(curR_, clampPct(tgtR_));
    writeSide(true,  curL_);
    writeSide(false, curR_);
}

void Motors::writeSide(bool isLeft, int16_t pct) {
    const uint8_t pinA = isLeft ? PIN_MOTOR_L_IN1 : PIN_MOTOR_R_IN3;
    const uint8_t pinB = isLeft ? PIN_MOTOR_L_IN2 : PIN_MOTOR_R_IN4;
    const uint8_t chA  = isLeft ? CH_L_IN1 : CH_R_IN3;
    const uint8_t chB  = isLeft ? CH_L_IN2 : CH_R_IN4;

    int16_t mag = pct < 0 ? (int16_t)-pct : pct;
    if (mag != 0 && mag < MOTOR_MIN_PCT) mag = MOTOR_MIN_PCT;   // below this it buzzes
    if (mag > ceiling_) mag = ceiling_;
    const uint32_t duty = (uint32_t)mag * 255u / 100u;

    // One pair of these is unused, depending on the core version: 3.x binds
    // PWM to the pin, 2.x to a channel. Silence both rather than #if here.
    (void)pinA; (void)pinB; (void)chA; (void)chB;
    if (pct > 0) {
        PWM_WRITE(pinB, chB, 0);
        PWM_WRITE(pinA, chA, duty);
    } else if (pct < 0) {
        PWM_WRITE(pinA, chA, 0);
        PWM_WRITE(pinB, chB, duty);
    } else {
        PWM_WRITE(pinA, chA, 0);
        PWM_WRITE(pinB, chB, 0);
    }
}

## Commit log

2026-09-11 Initial commit: DUST-E project complete
    Compilable Arduino firmware for ESP32-S3 and ESP32-C3, parametric OpenSCAD CAD
    for all 24 3D-printed parts, complete wiring and assembly documentation, bill of
    materials, test plan, and demo script.
    Five core capabilities: observes approaching users, detects thrown objects,
    intentionally disobeys remote commands via deterministic mistranslation engine,
    self-disables NORMAL MODE via mechanical finger, and prioritizes safety above
    all else with dual-channel obstruction detection and eased lid motion.
    Non-blocking state machines throughout. Nothing is glued. Designed to degrade
    rather than fail. First bring-up is a compile-and-calibration.
    [BOM.csv, binchad_params.scad, chassis_and_tray.scad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]
2026-09-15 Add eyes, speaker and servo hands to the web build; companion brain
    Web remote (ESP32 + L298N):
    - src/face: two SSD1306 OLED eyes, 14 parametric expressions rendered in a
    core-0 task; probed over I2C and reported ONLINE/MISSING.
    - src/sound/speaker: MAX98357A I2S playback of WAV, MP3 (incl. MP3-in-WAV)
    and ADTS AAC via ESP8266Audio 1.9.9; the phone shows instead of echoing.
    - src/hands: two servos, 12 keyframed gestures with angle and slew limits;
    e-stop parks them slowly and cuts the pulses.
    - src/body: one event -> expression/gesture table driven by the sound bank
    listener; gesture and face test buttons on the HW tab.
    - docs: body kit page with expression gallery, wiring a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
    [body.cpp, default.yaml]
2026-09-15 Name the project and every robot DUST-E
    - Firmware: firmware/DustE (the bin), DustERemote, DustEWeb (web rover),
    DustECam (camera board); brain/dustebrain; cad/duste_params.scad.
    - Dashboard DUST-E OS, BLE name DUST-E, mDNS http://dust-e.local,
    AP DUST-E-SETUP / dustebin (camera board matches), DUSTE_* macros.
    - DEMO.md is the demo script.
    - NVS namespace is kept behind NVS_NAMESPACE so a flashed board keeps its
    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
    [BOM.csv, binchad_params.scad, chassis_and_tray.scad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]
2026-09-19 Add Phase 2 body link/safety/dashboard, sensor node, and vision streaming
    Brings the companion architecture plan to a working, tested state:
    - brain/dustebrain/body/: wire protocol (CRC-16 JSON lines), command
    validator (source policy, clamps, rate limits), and SimBody - a Python
    reference implementation of the XIAO's reflex safety, tested against the
    failsafe matrix in docs/COMPANION_ARCHITECTURE.md section 8.1.
    - brain/dustebrain/body/link.py + apps/body_probe.py: BodyLink, the real
    serial client (SerialTransport/LoopbackPipe), and a bring-up CLI.
    - brain/dustebrain/dashboard/: the Phase 2 DRIVE + HW + DEBUG web dashboard,
    stdlib HTTP only, tested end-to-end over real sockets ag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
    [DustEBody.ino, DustESensorNode.ino, brainLink.cpp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]

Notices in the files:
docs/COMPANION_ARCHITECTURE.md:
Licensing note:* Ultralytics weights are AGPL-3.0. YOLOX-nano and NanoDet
